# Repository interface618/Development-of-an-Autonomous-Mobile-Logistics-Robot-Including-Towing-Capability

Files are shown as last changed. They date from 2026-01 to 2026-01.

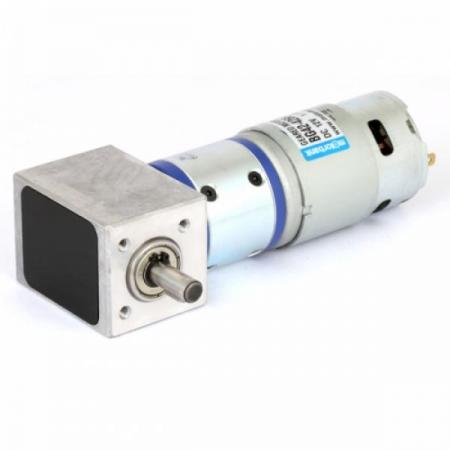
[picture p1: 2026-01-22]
HowToMake/BG42-4266.jpg

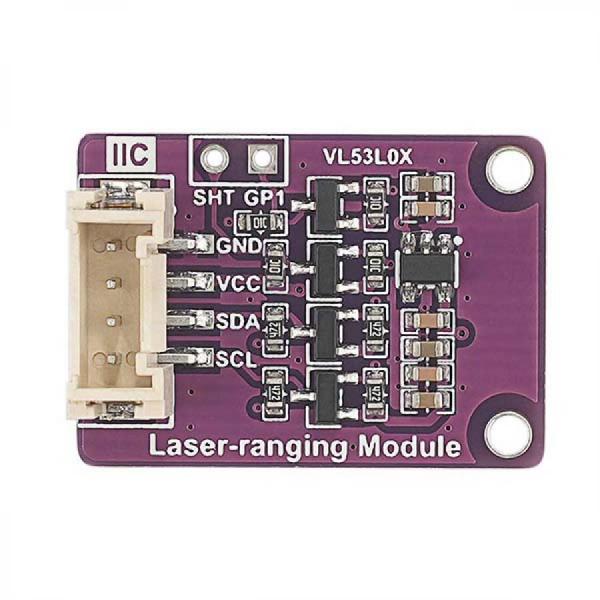
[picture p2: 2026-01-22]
HowToMake/VL53L0X.jpg

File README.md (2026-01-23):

<p align='center'>


<div align="center">
<h2>[2025] 견인기능을 포함한 물류로봇 </h2>
본 시스템은 고장 로봇 발생 시 별도의 인력 개입 없이 작업 흐름을 유지할 수 있도록 하여 다운타임을 감소시키고, 운영 비용 절감과 처리 효율 향상을 가능하게 한다. 더 나아가 로봇 간 협업 기반 자동 복구 체계를 구축함으로써 물류 시스템의 복원 탄력성과 고가용성 확보에 기여하며, 스마트 물류센터 및 무인 물류 환경으로의 확장 가능성을 제공한다.
</div>

## 목차
  - [개요](#개요) 
  - [작품 설명](#작품-설명)
  - [작품 작동 방식](#작품-작동-방식)
  - [역할 및 내용](#역할-및-내용)
  - [트러블 슈팅](#트러블-슈팅)
  - [코멘트](#코멘트)

## 개요
- 프로젝트 이름: 견인기능을 포함한 물류로봇
- 프로젝트 기간: 2025.01-2025.12
- 개발 엔진 및 언어: C & C++ & Python 
- 멤버: Interface (이윤승 ,박승규 ,최성원 ,김혁진)

## 작품 설명
본 작품은 자율이동로봇(AMR) 환경에서 고장 로봇을 정상 로봇이 자율적으로 인식하고 도킹·견인하여 물류 작업 흐름을 유지하는 자동 복구형 협업 로봇 시스템이다. 다중 센서 융합 기반 정렬 및 결합 메커니즘과 견인 모드 전환에 따른 제어 파라미터 자동 조정을 통해 하중 변화에 안정적으로 대응할 수 있도록 설계되었다. 이를 통해 물류센터 내 작업 중단을 최소화하고 운영 안정성과 고가용성을 확보한다.

## 작품 작동 방식


https://youtu.be/UkVe2rLXZ-U<br>

또는 demonstration video참조<br>

## 역할 및 내용

<table align="center">
  <thead>
    <tr>
      <th align="center">이름</th>
      <th align="center">역할</th>
      <th align="center">내용</th>
    </tr>
  </thead>
  <tbody>
    <tr>
      <td nowrap align="center">이윤승</td>
      <td align="center">프로젝트 총괄<br>견인 시 주행 안정화 알고리즘 개발<br>멀티로봇 시스템 개발<br>관제 시스템 개발</td>
      <td align="center">견인 시 주행 불안정성 완화를 위한 알고리즘 개발<br>멀티 로봇 제어를 위한 환경 구축<br>멀티로봇의 작업 스케쥴러 생성<br>관제시스템 UI 제작</td>
    </tr>
    <tr>
      <td nowrap align="center">박승규</td>
      <td align="center">모터 제어<br>센서 데이터 수집</td>
      <td align="center">STM32 기반 엔코더 속도 측정 및 모터 PWM 제어 루프 구현<br>목표 선속도/각속도 추종을 위한 증분형 PID 제어기 적용<br>견인/비견인 모드 전환 시 PID 게인 자동 스위칭 구조 설계<br>엔코더 값을 이용해 Dead-reckoning 오도메트리로 (x, y, yaw) 위치를 추정<br>IMU + 2D LiDAR EKF 융합으로 장기 드리프트 보정</td>
    </tr>
    <tr>
      <td nowrap align="center">최성원</td>
      <td align="center">영상인식 장치 제작<br>자율주행 알고리즘 개발<br>로봇정렬</td>
      <td align="center">카메라 기반 영상 인식 장치 설계 및 ROS2 연동, 로봇 전방 환경 및<br> 도킹 대상 인식을 위한 영상 처리 파이프라인 구성<br>
영상 인식 결과를 이용한 로봇 정렬 알고리즘 설계<br>
목표 위치·각도 오차에 따른 단계적 접근 로직 구성</td>
    </tr>
    <tr>
      <td nowrap align="center">김혁진</td>
      <td align="center">외관 제작<br>내부 설계 제작<br>회로도 제작<br>센서 데이터 수집</td>
      <td align="center">3D프린터를 이용한 외관제작<br>소자간의 밀집도가 높은 회로도 제작<br>회로도, 베터리, 젯슨오린나노 등 모듈간의 밀집도높은 내부 설계</td>
    </tr>
  </tbody>
</table>

## 트러블 슈팅
- **견인 모드에서 주행 불안정(피시테일) 발생**
  - 문제: 고장 로봇을 견인해 안전/정비 구역으로 이동 중, 피시테일이 발생하여 경로를 이탈함.
  - 원인: 견인 하중이 후방에 집중되면서 yaw 관성 및 응답 지연이 증가해, 기존 경로추종 제어에서 회전 오버슈트가 반복적으로 증폭됨.
  - 해결: 경로 상 2개 예측점으로 목표 방향각(heading angle)을 atan2 기반으로 계산하고, 목표 방향각(heading angle)이 임계각과 비교하여 초과하면 선속도를 제한한 뒤 각속도 우선으로 heading을
          먼저 정렬하고, 정렬 완료 후 경로 추종을 재개하도록 제어 로직을 분기함.
  - 결과: 동일 조건 반복 시험에서 경로 평균 오차가 0.4 m → 0.1 m로 감소함.
 
- **로봇의 크기와 무게 문제**
  - 문제: 로봇의 크기와 무게가 예상보다 커 줄일 필요가 생겼습니다.
  - 원인: 필요이상의 많은 소자를 사용하고 소자간의 밀집도가 떨어져 로봇 모델의 크기가 커졌습니다.
  - 해결: 중요도가 떨어지는 소자를 줄이고 소자간의 밀집도를 중심으로 재설계를 했습니다.
  - 결과: 로봇 모델의 무게를 10 ~ 11kg에서 7kg로 줄이고 크기도 줄였습니다.
 
- **후크모양에서 생기는 전류문제**
  - 문제: 견인이 성공하는 구역을 넓게하고 피견인 로봇을 높게 들게 설계를 할시 엑추에이터가 너무 많은 전류를 필요로하는 문제가 생겼습니다.
  - 원인: 2개의 엑추에이터에서 견인을 하는것을 1개의 지지대와 1개의 엑추에이터로 견인을 하게 재설계를 하여 문제가 발생하였습니다.
  - 해결: 후크구조에 임의로 3가지의 변수를 만들어 변수의 길이와 각도를 조절하며 최적의 후크구조를 찾아 해결하였습니다.
  - 결과: 최대 전류 0.1A로 견인을 할수있게 되었습니다.

- **견인 모드 하중 변화로 인한 주행 오차 증가**
  - **문제:** 견인 상태에서 속도·자세(heading) 오차가 커지며 경로 추종 안정성이 저하됨
  - **원인:** 견인 하중 증가로 시스템 동특성(관성/저항)이 변해 기존 PID 이득으로는 추종 성능이 부족함
  - **해결:** **견인 모드 전용 PID 제어 이득을 재조정(튜닝)**하고, 견인/비견인 모드에 따라 이득을 분리 적용
  - **결과:** 견인 주행 시 속도·자세 오차가 감소하고 경로 추종이 안정화됨

- **Dead-reckoning 기반 오도메트리 누적 드리프트**
  - **문제:** 장시간 주행 시 (x, y, yaw) 추정값이 누적 오차로 인해 실제 위치와 점점 벌어짐
  - **원인:** 엔코더 기반 Dead-reckoning은 슬립, 노면 변화, 엔코더/시간 동기 오차가 누적되어 장기 드리프트가 발생함
  - **해결:** IMU + 2D LiDAR를 EKF로 융합하여 오도메트리 예측값을 센서 측정으로 주기적으로 보정
  - **결과:** 장기 드리프트가 억제되어 위치추정 신뢰도가 향상되고 도킹/견인 시 정렬 안정성이 개선됨

  **영상 인식 기반 로봇 정렬 오차 및 인식 불안정성**
  - 문제: 조명·각도·가림(occlusion) 영향으로 영상 인식 기반 상대 위치/각도 추정이 흔들려 도킹 정렬이 불안정해짐

  - 원인: 단일 카메라 인식은 환경 변화에 민감하고 프레임 간 추정값이 튀어 제어 입력이 급격히 변할 수 있음

  - 해결: 영상 인식 결과를 정렬 목표값으로 사용하되 레이저 센서 등 보조 정보로 제어를 안정화하고 인식 노이즈를 완화

  - 결과: 인식 불안정이 줄어 정렬 성공률이 향상되고 도킹/견인 단계 결합 신뢰도가 개선됨
  
## 코멘트

- PID 게인을 실험적으로 조정해 성능을 맞췄지만, 시간·환경 제약으로 충분한 반복 실험 데이터를 쌓지 못한 점이 아쉬웠습니다. 다음에는 더 다양한 조건에서 데이터를 축적해 근거 기반으로 최적 게인을 도출하고 싶습니다.
- 너무 회로도와 내부 설계 밀집도만 집중해서 내부온도와 같이 중요한 부분을 놓친게 많아 아쉽다.
- 게인과 임계값을 경험적으로 맞춰 동작은 확보했지만, 하중/바닥 마찰/배터리 전압 변화까지 포함한 체계적인 튜닝 실험과 데이터 기반 최적화가 부족했다. 동일 조건 반복 실험을 통해 최적의 게인 값을 구하여 로봇이 안정적이게 움직일 수 있도록 시도 해 볼 가치가 있다.
- ArUco 마커 기반 인식은 정렬 정확도가 높고 구현이 간단하다는 장점이 있으나, 마커 훼손·가림·부착 관리가 필요한 구조적 한계가 있다. 본 연구에서는 해당 방식에 의존하였다는 점에서 실제 현장 적용성을 충분히 고려하지 못한 아쉬움이 있다. 향후에는 로봇의 형상과 외관 특징을 학습한 객체 인식 모델을 활용하여 마커 없는 정렬 방식을 적용함으로써 시스템의 실용성과 확장성을 높이고자 한다.
- 실물 로봇을 만들기전에 Gazebo 시뮬레이션을 사용해보고 했으면 시행착오가 덜 했을것 같다는 생각이 들었다 다음에는 시뮬레이션을 돌려보고 실물 로봇 제작을 해야할것 같다.
- 생각보다 C/C++/Python을 사용을 잘 못하는 것 같다 코딩 테스트나 공부를 더해야겠다는 생각이 들었다.
- 내가 만든 알고리즘을 논문이나 발표자료에 수식으로 표현해야하는데 수학적인 지식이 부족해서 표현하는데 힘들었던 것 같다 선형대수학과 미적분학, 확률과 통계에 대한 공부를 더 해야겠다는 생각이 들었다

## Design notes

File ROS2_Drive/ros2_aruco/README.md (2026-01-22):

# ros2_aruco

ROS2 Wrapper for OpenCV Aruco Marker Tracking

This package depends on a recent version of OpenCV python bindings and transforms3d library:

```
pip3 install opencv-contrib-python transforms3d
```

## ROS2 API for the ros2_aruco Node

This node locates Aruco AR markers in images and publishes their ids and poses.

Subscriptions:
* `/camera/image_raw` (`sensor_msgs.msg.Image`)
* `/camera/camera_info` (`sensor_msgs.msg.CameraInfo`)

Published Topics:
* `/aruco_poses` (`geometry_msgs.msg.PoseArray`) - Poses of all detected markers (suitable for rviz visualization)
* `/aruco_markers` (`ros2_aruco_interfaces.msg.ArucoMarkers`) - Provides an array of all poses along with the corresponding marker ids

Parameters:
* `marker_size` - size of the markers in meters (default .0625)
* `aruco_dictionary_id` - dictionary that was used to generate markers (default `DICT_5X5_250`)
* `image_topic` - image topic to subscribe to (default `/camera/image_raw`)
* `camera_info_topic` - Camera info topic to subscribe to (default `/camera/camera_info`)
* `camera_frame` - Camera optical frame to use (default to the frame id provided by the camera info message.)

## Running Marker Detection

1. Using the launch file - parameters will be loaded from _aruco\_parameters.yaml_.
```
ros2 launch ros2_aruco aruco_recognition.launch.py
```
2. As a single ROS 2 node - you can specify parameter values at startup by adding `--ros-args -p marker_size:=.05`, for example.
```
ros2 run ros2_aruco aruco_node
```

## Generating Marker Images

```
ros2 run ros2_aruco aruco_generate_marker
```

Pass the `-h` flag for usage information: 

```
usage: aruco_generate_marker [-h] [--id ID] [--size SIZE] [--dictionary]

Generate a .png image of a specified maker.

optional arguments:
  -h, --help     show this help message and exit
  --id ID        Marker id to generate (default: 1)
  --size SIZE    Side length in pixels (default: 200)
  --dictionary   Dictionary to use. Valid options include: DICT_4X4_100,
                 DICT_4X4_1000, DICT_4X4_250, DICT_4X4_50, DICT_5X5_100,
                 DICT_5X5_1000, DICT_5X5_250, DICT_5X5_50, DICT_6X6_100,
                 DICT_6X6_1000, DICT_6X6_250, DICT_6X6_50, DICT_7X7_100,
                 DICT_7X7_1000, DICT_7X7_250, DICT_7X7_50, DICT_ARUCO_ORIGINAL
                 (default: DICT_5X5_250)
```

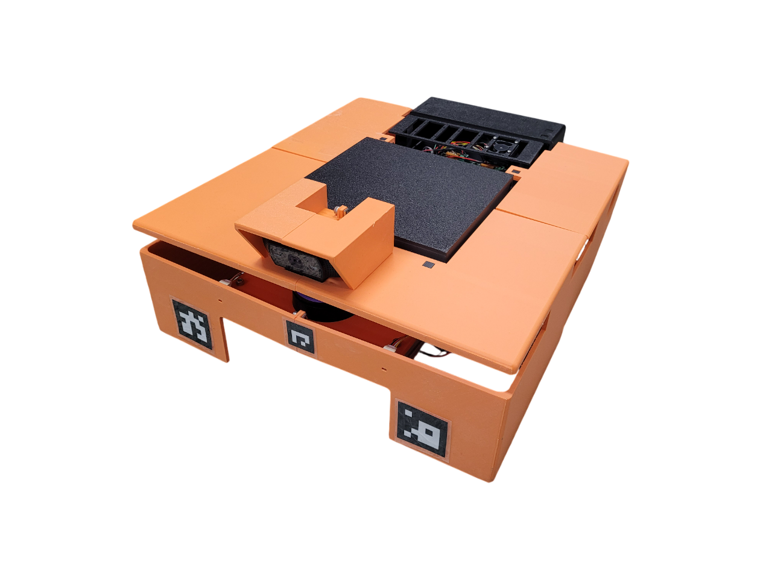
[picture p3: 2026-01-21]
3D/full1.png

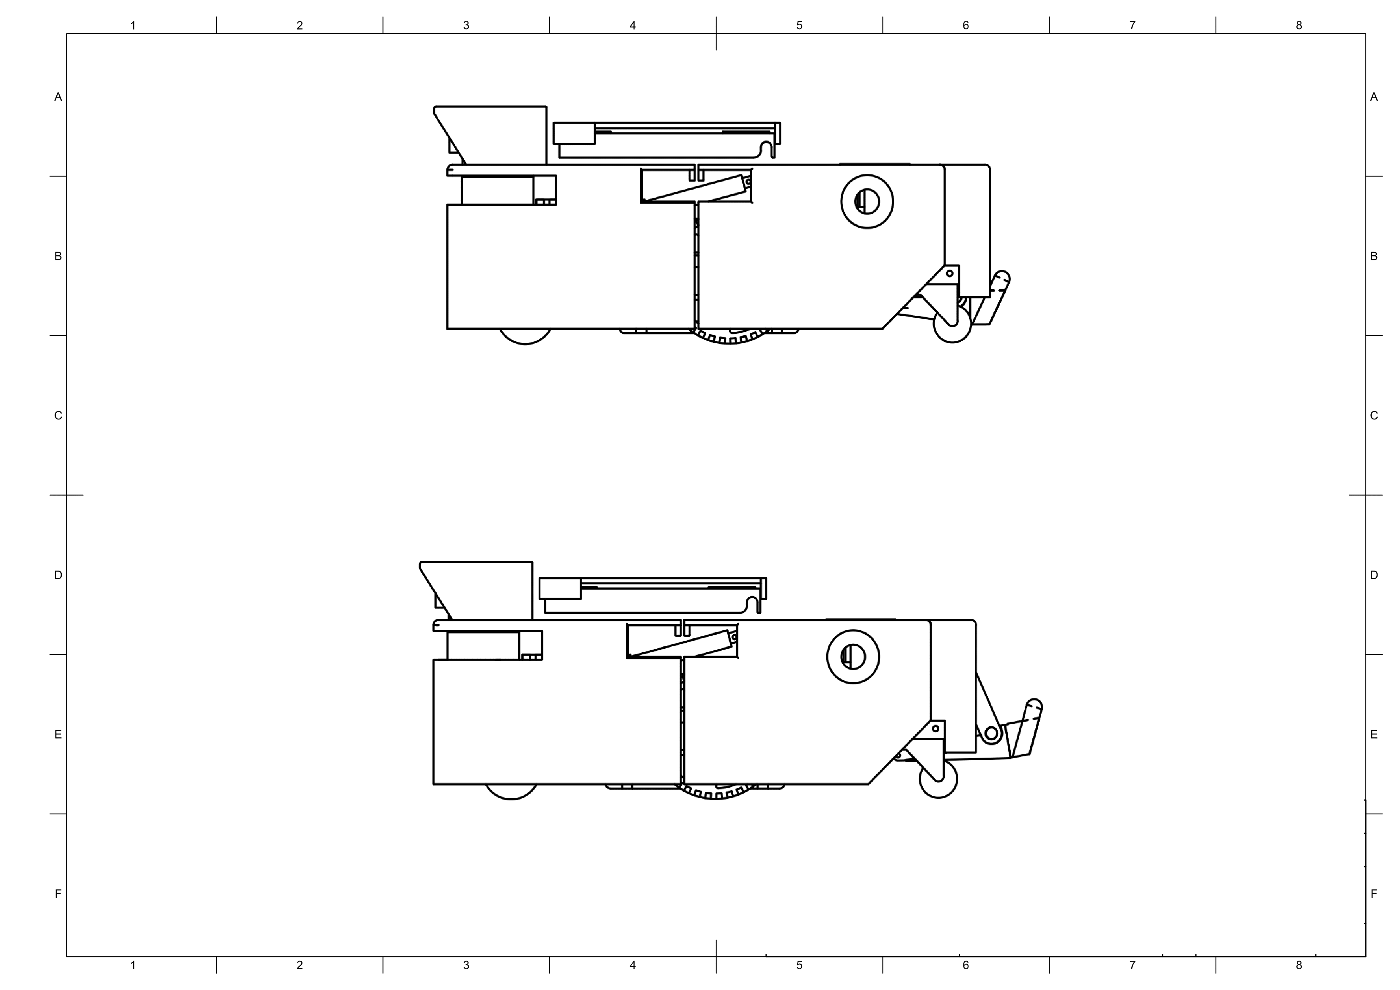
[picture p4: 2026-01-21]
3D/hook_updown.png

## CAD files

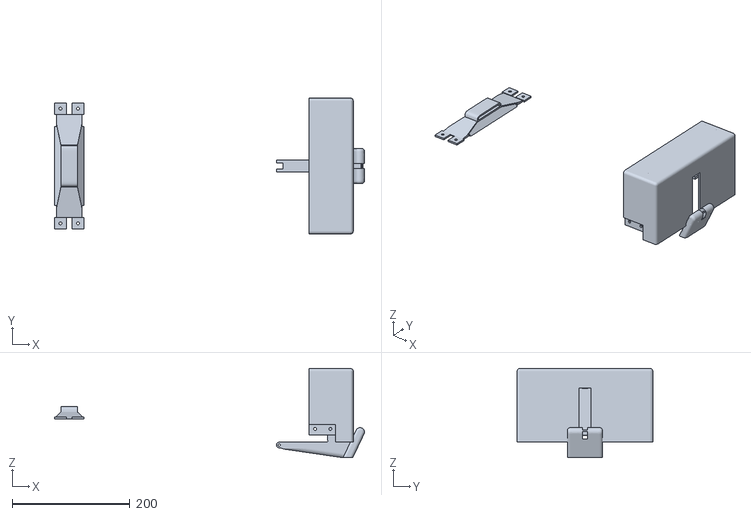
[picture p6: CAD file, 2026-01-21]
3D/hook.stl
527.3 x 231.2 x 151.6

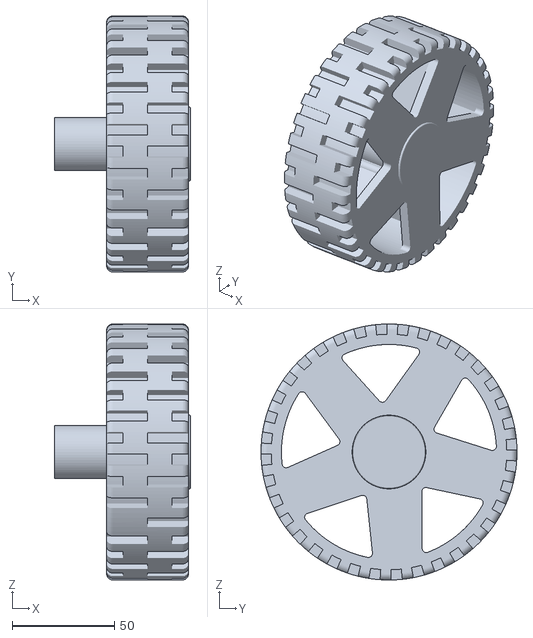
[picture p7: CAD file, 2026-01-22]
ROS2_Drive/shark_urdf/meshes/wheel.stl
66.5 x 125.0 x 125.0

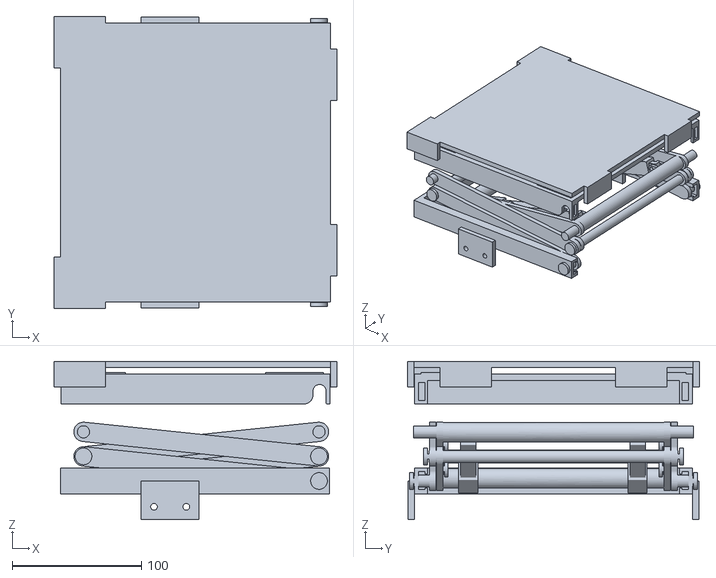
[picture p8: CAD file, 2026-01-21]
3D/lift.stl
219.0 x 226.0 x 122.6

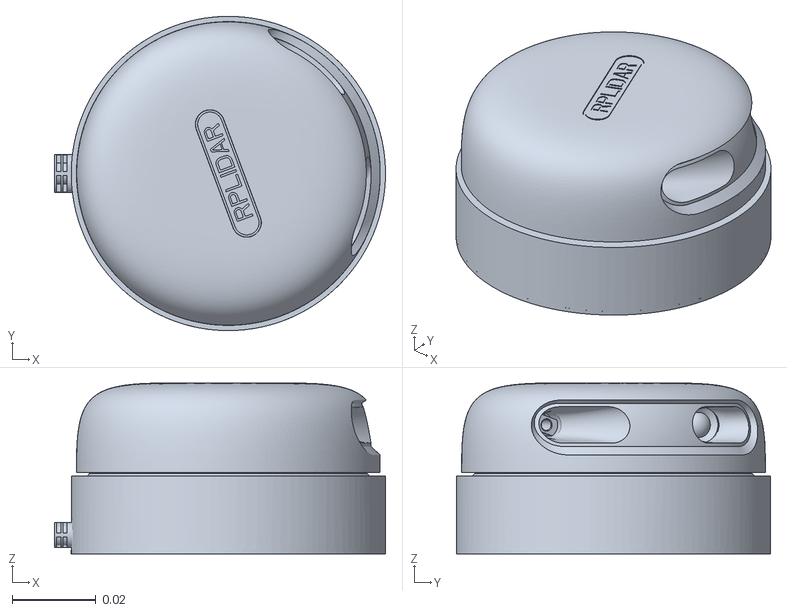
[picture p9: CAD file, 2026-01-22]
ROS2_Drive/shark_urdf/meshes/rplidar-a2.stl
0.079 x 0.075 x 0.0408

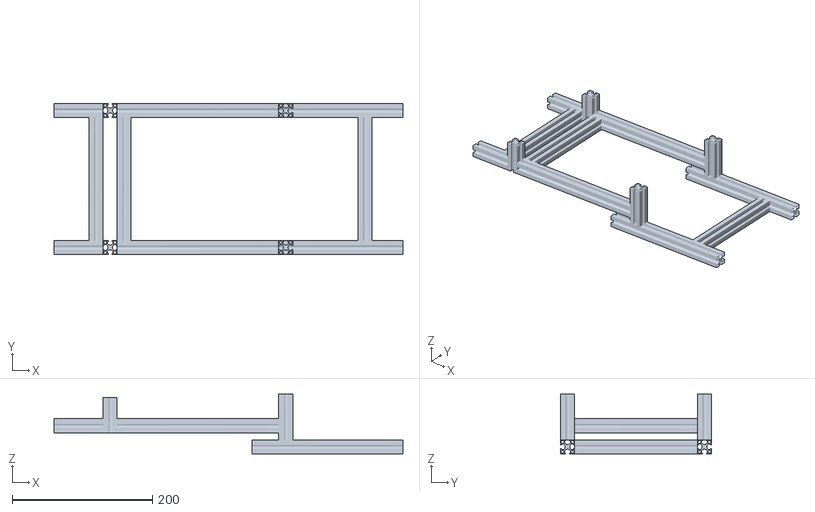
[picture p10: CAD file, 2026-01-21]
3D/frame.stl
497.0 x 215.0 x 85.0

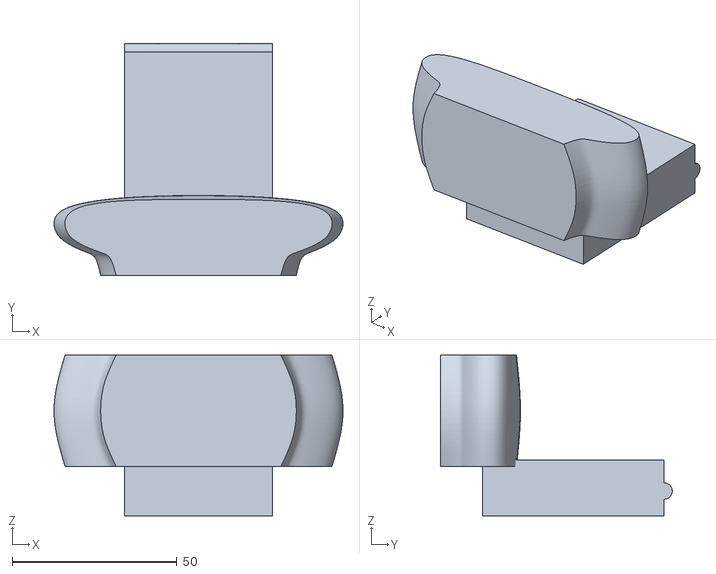
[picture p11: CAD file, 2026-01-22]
ROS2_Drive/shark_urdf/meshes/webcam.stl
87.6 x 70.2 x 48.7

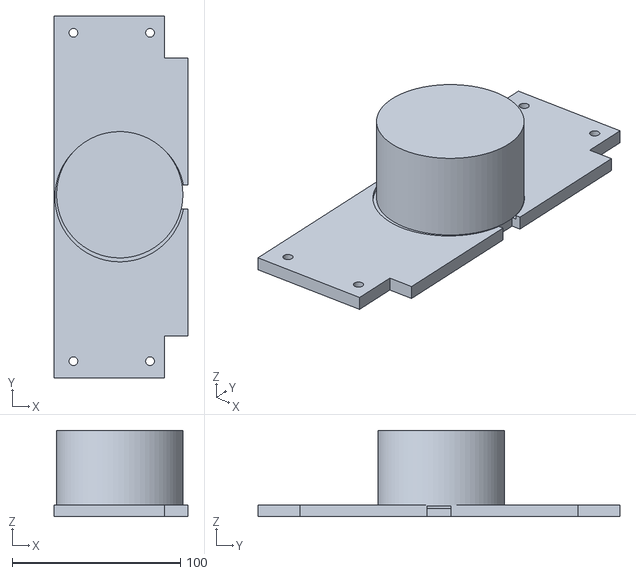
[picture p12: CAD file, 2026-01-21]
3D/lidar.stl
79.5 x 215.0 x 51.4

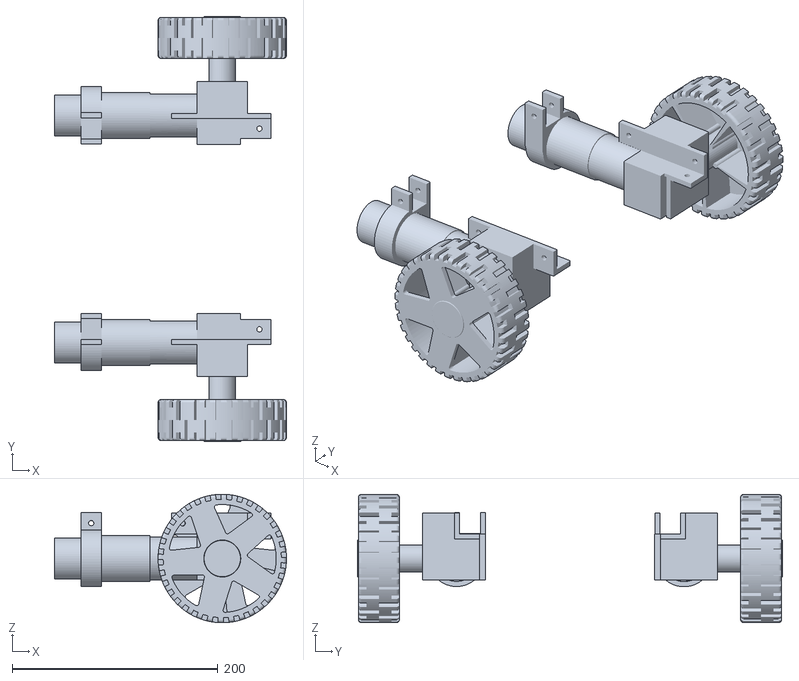
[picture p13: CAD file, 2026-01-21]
3D/motor.stl
225.8 x 413.9 x 125.0

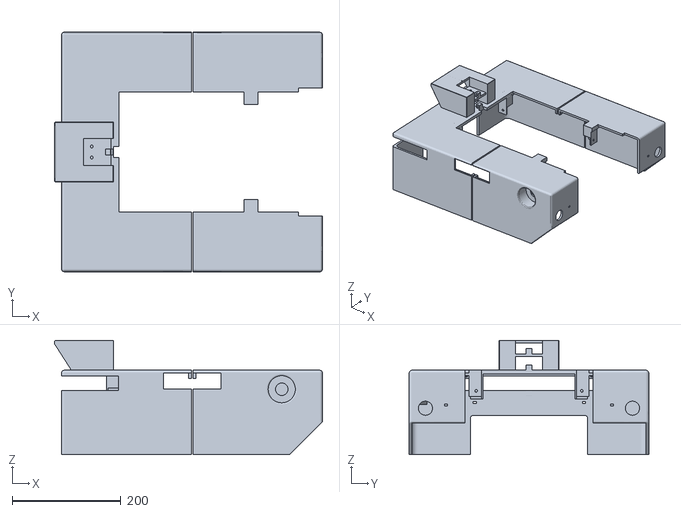
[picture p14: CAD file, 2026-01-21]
3D/bumper.stl
493.6 x 441.3 x 210.5

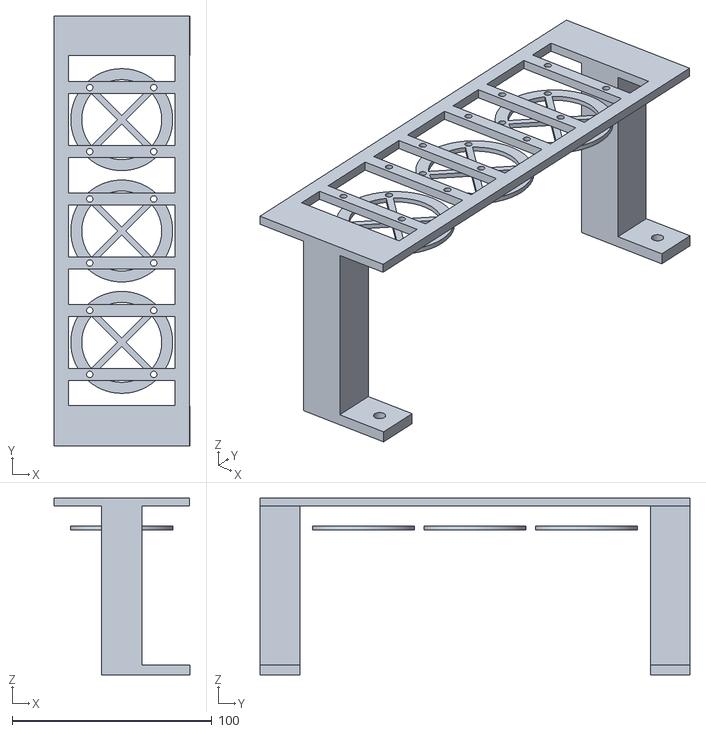
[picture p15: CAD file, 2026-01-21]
3D/cooler.stl
67.8 x 215.0 x 88.5

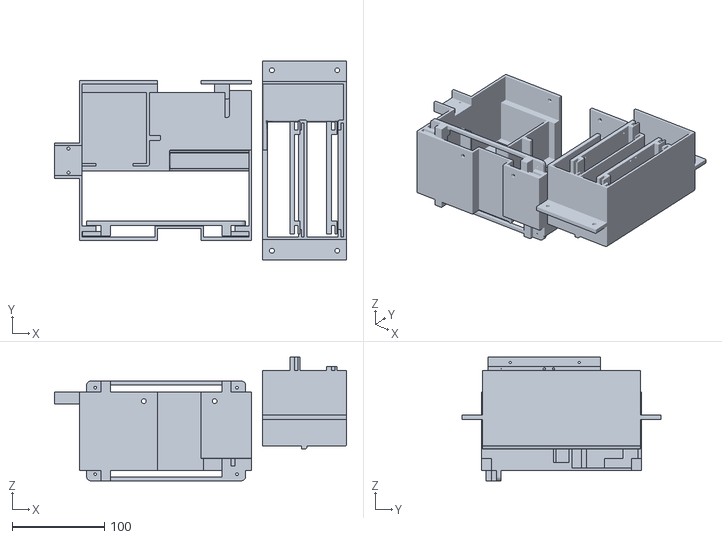
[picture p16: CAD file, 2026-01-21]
3D/box.stl
317.2 x 216.0 x 134.4

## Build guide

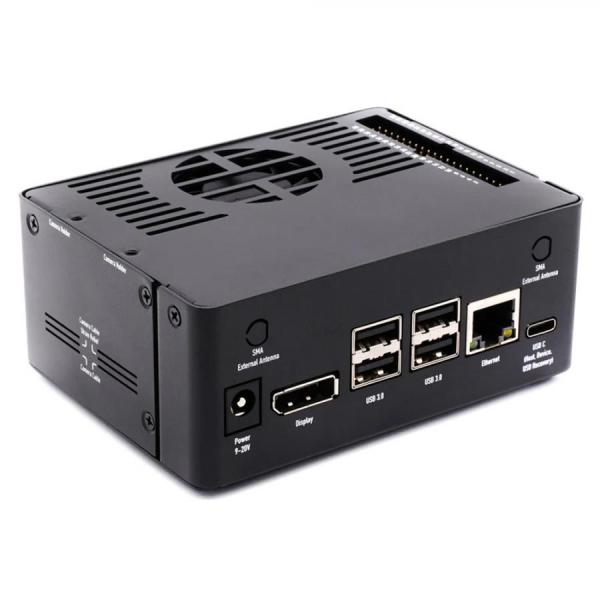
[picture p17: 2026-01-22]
HowToMake/NVIDIA Jetson Orin Nano.jpg

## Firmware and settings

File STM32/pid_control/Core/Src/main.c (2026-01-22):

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
/* Includes ------------------------------------------------------------------*/
#include "main.h"

/* USER CODE BEGIN Includes */
#include <stdio.h>
#include <math.h>
#include <stdlib.h>
#include <string.h>
#include "stm32f4xx.h"
#include "VL53L0X.h"

/* USER CODE END Includes */

/* USER CODE BEGIN PTD */
extern I2C_HandleTypeDef VL53L0X_I2C_Handler;

/* USER CODE END PTD */

I2C_HandleTypeDef hi2c1;
I2C_HandleTypeDef hi2c2;

TIM_HandleTypeDef htim2;
TIM_HandleTypeDef htim3;
TIM_HandleTypeDef htim5;

UART_HandleTypeDef huart2;

/* USER CODE BEGIN PV */
/*=======================================RAZER=======================================*/
statInfo_t_VL53L0X distanceL_stats;
statInfo_t_VL53L0X distanceR_stats;
uint16_t distanceL = 0; // volatile 추가
uint16_t distanceR = 0; // volatile 추가


#define FILTER_BUFFER_SIZE 10
volatile uint16_t distanceL_buffer[FILTER_BUFFER_SIZE] = {0};
volatile uint16_t distanceR_buffer[FILTER_BUFFER_SIZE] = {0};
int buffer_index_L = 0;
int buffer_index_R = 0;
/*=======================================RAZER=======================================*/
/* USER CODE END PV */

void SystemClock_Config(void);
static void MX_GPIO_Init(void);
static void MX_USART2_UART_Init(void);
static void MX_TIM5_Init(void);
static void MX_TIM2_Init(void);
static void MX_I2C1_Init(void);
static void MX_I2C2_Init(void);
static void MX_TIM3_Init(void);
/* USER CODE BEGIN PFP */
#ifdef __GNUC__
#define PUTCHAR_PROTOTYPE int __io_putchar(int ch)
#else
#define PUTCHAR_PROTOTYPE int fputc(int ch, FILE *f)
#endif

PUTCHAR_PROTOTYPE {
	if (ch == '\n')
		HAL_UART_Transmit(&huart2, (uint8_t*) "\r", 1, 0xFFFF);
	HAL_UART_Transmit(&huart2, (uint8_t*) &ch, 1, 0xFFFF);
	return ch;
}


/*=============================DT=============================*/
extern volatile uint32_t msTicks;   // SysTick 1ms 카운터
#define DT_S          0.039f      // 39 ms 고정 주기
/*=============================DT=============================*/

/*=========================Encoder value=========================*/
volatile int32_t left_encoder_value = 0;    //left
volatile int32_t right_encoder_value  = 0;  //right

volatile int32_t prev_count_L = 0;
volatile int32_t prev_count_R = 0;
/*=========================Encoder value=========================*/

/*============================motor============================*/
#define WHEEL_RADIUS    0.0625f    // 바퀴 반지름 (단위: m)
#define WHEEL_BASE      0.33f    // 바퀴 간 거리 (단위: m)
#define ENCODER_RES     3172       // 엔코더 분해능 (4체배 적용된 값)
volatile int32_t tow = 0;
volatile int32_t tow_applied = 0;
/*============================motor============================*/

/*=============================PID=============================*/
float Kp = 4, Kd = 1.6, Ki = 8;
float P_term = 0, D_term = 0, I_term = 0;
float pid = 0;

float Kp_a = 5, Kd_a = 1.3, Ki_a = 6.25;
float P_term_a = 0, D_term_a = 0, I_term_a = 0;
float pid_a = 0;

float error = 0;
float previous_error = 0;
float old_error = 0;

float error_a = 0;
float previous_error_a = 0;
float old_error_a = 0;

float speed = 0;
float speed_r = 0;

double angle = 0.0019808276504349264;   // will fix (rad/count)

/*=============================MID=============================*/
volatile int32_t delta_cnt_L = 0;
volatile int32_t delta_cnt_R = 0;
float   dtheta_L    = 0.0f;    // [rad]
float   dtheta_R    = 0.0f;    // [rad]
float   dist_L      = 0.0f;    // [m]
float   dist_R      = 0.0f;    // [m]
float   s_step      = 0.0f;    // [m/period]
float   theta_step  = 0.0f;    // [rad/period]
float   v_meas      = 0.0f;    // [m/s]
float   w_meas      = 0.0f;    // [rad/s]
/*=============================MID=============================*/

/*=============================PID=============================*/


/*=============================USART=============================*/
char rx_buffer[256];
char rx_data;
int rx_index = 0;

int stop_flag = 0;
int sent_flag = 0;  // 전송 여부 상태 저장

// 1. ROS에서 받은 선속도/각속도 값 (단위: m/s, rad/s)
float cmd_vel_x = 0.0;  // v
float cmd_vel_z = 0.0;  // w

/*=============================USART=============================*/

/*=============================DIR=============================*/
void check_move_state();
void check_move_state_r();
void motorControl(int in1, int in2);
void motorControl_r(int in1, int in2);

int control_1 = 0, control_2 = 1;
int control_1_r = 1, control_2_r = 0;

int move_state = 0;  // front:0 back:1
int move_state_r = 0;
/*=============================DIR=============================*/

/*=============================PWM=============================*/
void Pwm_Left(int pwm_input);
void Pwm_Right(int pwm_input);
void check_pwm();
void check_pwm_r();
/*=============================PWM=============================*/


/*=============================RK2=============================*/
double odom_x = 0.0;     // [m]
double odom_y = 0.0;     // [m]
double odom_th = 0.0;    // [rad]

double previous_odom_x = 0.0;
double previous_odom_y = 0.0;
double previous_odom_th = 0.0;

double value = 0.0;
double dtt = 0.0;

/*=============================RK2=============================*/

/*=============================RAZER=============================*/
void apply_sensor_config(void);
uint16_t get_filtered_distance(volatile uint16_t* buffer, int* index, uint16_t new_distance);
/*=============================RAZER=============================*/
/*=============================SWITCH=============================*/
void limited_switch();
int switch_flag = 0;
int switch_count = 0;
/*=============================SWITCH=============================*/

/* USER CODE END PFP */

/**
  * @brief  The application entry point.
  * @retval int
  */
int main(void)
{

  /* MCU Configuration--------------------------------------------------------*/

  /* Reset of all peripherals, Initializes the Flash interface and the Systick. */
  HAL_Init();

  /* Configure the system clock */
  SystemClock_Config();

  /* Initialize all configured peripherals */
  MX_GPIO_Init();
  MX_USART2_UART_Init();
  MX_TIM5_Init();
  MX_TIM2_Init();
  MX_I2C1_Init();
  MX_I2C2_Init();
  MX_TIM3_Init();
  /* USER CODE BEGIN 2 */

  /*----------------------------------------------------*/
  HAL_TIM_PWM_Start(&htim5, TIM_CHANNEL_1);
  HAL_TIM_PWM_Start(&htim5, TIM_CHANNEL_2);


  /*----------------------------------------------------*/

  /*----------------------------------------------------*/
  motorControl(control_1,  control_2);
  motorControl_r(control_1_r, control_2_r);

  /*----------------------------------------------------*/
  HAL_UART_Receive_IT(&huart2, (uint8_t*)&rx_data, 1);
  HAL_TIM_Base_Start_IT(&htim2);
  /*----------------------------------------------------*/
  SystemCoreClockUpdate();
  SysTick_Config(SystemCoreClock / 1000);
  /*----------------------------------------------------*/

	//  // --- 센서 초기화 ---
	HAL_GPIO_WritePin(RAZER_POWER1_GPIO_Port, RAZER_POWER1_Pin, GPIO_PIN_SET);
	HAL_GPIO_WritePin(RAZER_POWER2_GPIO_Port, RAZER_POWER2_Pin, GPIO_PIN_SET);

	VL53L0X_I2C_Handler = hi2c1;
	if (initVL53L0X(1, &hi2c1)) {
		apply_sensor_config(); // 안정적인 330ms 설정 적용
	}

	VL53L0X_I2C_Handler = hi2c2;
	if (initVL53L0X(1, &hi2c2)) {
		apply_sensor_config();
	}

	// --- 첫 측정 시작 ---
	VL53L0X_I2C_Handler = hi2c1;
	startSingleMeasurement_nonBlocking();
	VL53L0X_I2C_Handler = hi2c2;
	startSingleMeasurement_nonBlocking();
  /*----------------------------------------------------*/
  /* USER CODE END 2 */

  /* Infinite loop */
  /* USER CODE BEGIN WHILE */
	while (1) {



		limited_switch();

		//방향 제어
		motorControl(control_1, control_2);
		motorControl_r(control_1_r, control_2_r);
		//PWM 제어
		Pwm_Left(fabsf(speed));
		Pwm_Right(fabsf(speed_r));

		/******** PID only + v,w print (전역 변수만 사용) ********/
		if (msTicks >= 39) {
			dtt = msTicks;

			/*************************** TOW ******************************/
			if (tow == 1 && tow_applied == 0)
			{
				//KP,KI,KD 값 변경
			    Kp   = Kp   * 1.25f;   Ki   = Ki   * 1.20f;   Kd   = Kd   * 0.90f;
			    Kp_a = Kp_a * 1.30f;   Ki_a = Ki_a * 1.20f;   Kd_a = Kd_a * 0.90f;

			    previous_error = old_error = 0.0f;
			    previous_error_a = old_error_a = 0.0f;

			    tow_applied = 1;
			}
			/*************************** TOW ******************************/

			/*************************** RAZER ******************************/
			// --- 센서 상태 확인 및 데이터 수신 (논블로킹) ---
			VL53L0X_I2C_Handler = hi2c1;
			if (isMeasurementReady()) {
				uint16_t raw_distanceL = readMeasurementResult(
						&distanceL_stats);
				// 필터링 및 범위 제한 적용
				if (distanceL_stats.rangeStatus == 0
						|| distanceL_stats.rangeStatus == 11) {
					distanceL = get_filtered_distance(distanceL_buffer,
							&buffer_index_L, raw_distanceL);
				}
				startSingleMeasurement_nonBlocking(); // 다음 측정 시작
			}

			VL53L0X_I2C_Handler = hi2c2;
			if (isMeasurementReady()) {
				uint16_t raw_distanceR = readMeasurementResult(
						&distanceR_stats);
				if (distanceR_stats.rangeStatus == 0
						|| distanceR_stats.rangeStatus == 11) {
					distanceR = get_filtered_distance(distanceR_buffer,
							&buffer_index_R, raw_distanceR);
				}
				startSingleMeasurement_nonBlocking(); // 다음 측정 시작
			}
			/*************************** RAZER ******************************/
			// 1) 이번 주기 엔코더 증가량
			delta_cnt_L = left_encoder_value - prev_count_L;
			delta_cnt_R = right_encoder_value - prev_count_R;
			prev_count_L = left_encoder_value;
			prev_count_R = right_encoder_value;

			// 2) 바퀴 각도[rad] → 선형 이동[m]
			dtheta_L = (float) delta_cnt_L * (float) angle;  // angle: rad/count
			dtheta_R = (float) delta_cnt_R * (float) angle;
			dist_L = dtheta_L * WHEEL_RADIUS;
			dist_R = dtheta_R * WHEEL_RADIUS;

			// 3) 이번 주기 전진/회전 변위
			s_step = 0.5f * (dist_R + dist_L);            // [m/period]
			theta_step = (dist_R - dist_L) / WHEEL_BASE;      // [rad/period]

			/******************** RK2 ***********************/
			value = previous_odom_th + (theta_step * 0.5f);
			odom_x = previous_odom_x + (s_step * cosf(value));
			odom_y = previous_odom_y + (s_step * sinf(value));
			odom_th = previous_odom_th + theta_step;

			previous_odom_x = odom_x;
			previous_odom_y = odom_y;
			previous_odom_th = odom_th;

			// 4) 측정 속도 환산
			v_meas = s_step / (dtt * 0.001f);                       // [m/s]
			w_meas = theta_step / (dtt * 0.001f);                     // [rad/s]

			/******************** PID ***********************/
			// 목표속도 - 측정속도
			error = (cmd_vel_x - v_meas);
			error_a = (cmd_vel_z - w_meas);

			// 증분형(Delta) 형태
			P_term = (error - previous_error) * Kp;
			D_term = (error - 2.0f * previous_error + old_error) * Kd;
			I_term = error * Ki;
			pid = P_term + D_term + I_term;

			P_term_a = (error_a - previous_error_a) * Kp_a;
			D_term_a = (error_a - 2.0f * previous_error_a + old_error_a) * Kd_a;
			I_term_a = error_a * Ki_a;
			pid_a = P_term_a + D_term_a + I_term_a;

			if (stop_flag == 0) {
				// 차동 결합: 선형(pid) ± 회전(pid_a)
				speed = speed + pid - pid_a;
				speed_r = speed_r + pid + pid_a;
			} else {
				speed = speed - (speed) / 5.0f;
				speed_r = speed_r - (speed_r) / 5.0f;
			}

			// 상태 갱신
			old_error = previous_error;
			old_error_a = previous_error_a;
			previous_error = error;
			previous_error_a = error_a;

			// PWM/상태 체크
			check_pwm();
			check_pwm_r();
			check_move_state();
			check_move_state_r();

			if (cmd_vel_x == 0 && cmd_vel_z == 0) {
				stop_flag = 1;
			} else {
				stop_flag = 0;
			}

			printf("# %f %f %f %f %f %f | %f %f %d\n", odom_x, odom_y, odom_th,
					dtt, v_meas, w_meas, (float)distanceL, (float)distanceR, switch_flag);


		}

    /* USER CODE END WHILE */

    /* USER CODE BEGIN 3 */
	}
  /* USER CODE END 3 */
}

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
/* USER CODE BEGIN 4 */

/*=========================Encoder value=========================*/
void HAL_GPIO_EXTI_Callback(uint16_t GPIO_Pin)
{

    if (GPIO_Pin == GPIO_PIN_15) // Left A
    {
        if (HAL_GPIO_ReadPin(GPIOB, GPIO_PIN_15) == HAL_GPIO_ReadPin(GPIOB, GPIO_PIN_14))
        {
            left_encoder_value--;
        }
        else
        {
            left_encoder_value++;
        }
    }
    else if (GPIO_Pin == GPIO_PIN_14) // Left B
    {
        if (HAL_GPIO_ReadPin(GPIOB, GPIO_PIN_15) == HAL_GPIO_ReadPin(GPIOB, GPIO_PIN_14))
        {
            left_encoder_value++;
        }
        else
        {
            left_encoder_value--;
        }
    }

    else if (GPIO_Pin == GPIO_PIN_12) // Right A
    {
        if (HAL_GPIO_ReadPin(GPIOA, GPIO_PIN_12) == HAL_GPIO_ReadPin(GPIOA, GPIO_PIN_11))
        {
            right_encoder_value++;
        }
        else
        {
            right_encoder_value--;
        }
    }
    else if (GPIO_Pin == GPIO_PIN_11) // Right B
    {
        if (HAL_GPIO_ReadPin(GPIOA, GPIO_PIN_12) == HAL_GPIO_ReadPin(GPIOA, GPIO_PIN_11))
        {
            right_encoder_value--;
        }
        else
        {
            right_encoder_value++;
        }
    }


    UNUSED(GPIO_Pin); // Prevent unused warning
}
/*=========================Encoder value=========================*/


/*=============================USART=============================*/
void HAL_UART_RxCpltCallback(UART_HandleTypeDef *huart) {
	if (huart->Instance == USART2) {
		if (rx_data != '\n') {
			rx_buffer[rx_index++] = rx_data;
		}
		else {
			rx_buffer[rx_index] = '\0';

			if (rx_buffer[0] == '1') {
				// 선속도 (cmd_vel_x) 추출
				char first_number[10];
				strncpy(first_number, &rx_buffer[2], 9);
				first_number[9] = '\0';
				cmd_vel_x = atof(first_number);
				if (rx_buffer[1] == '0') {
					cmd_vel_x = -cmd_vel_x;
				}

				// 각속도 (cmd_vel_z) 추출
				char second_number[10];
				strncpy(second_number, &rx_buffer[12], 9);
				second_number[9] = '\0';
				cmd_vel_z = atof(second_number);
				if (rx_buffer[11] == '0') {
					cmd_vel_z = -cmd_vel_z;
				}
			}
			else if (rx_buffer[0] == '3')
			{
                // 00
				HAL_GPIO_WritePin(GPIOA, GPIO_PIN_8, GPIO_PIN_RESET);
				HAL_GPIO_WritePin(GPIOA, GPIO_PIN_9, GPIO_PIN_RESET);
				HAL_GPIO_WritePin(GPIOC, GPIO_PIN_8, GPIO_PIN_RESET);
								HAL_GPIO_WritePin(GPIOC, GPIO_PIN_9, GPIO_PIN_RESET);
			}
			else if (rx_buffer[0] == '4')
			{
				//10
				HAL_GPIO_WritePin(GPIOA, GPIO_PIN_8, GPIO_PIN_SET);
				HAL_GPIO_WritePin(GPIOA, GPIO_PIN_9, GPIO_PIN_RESET);
				HAL_GPIO_WritePin(GPIOC, GPIO_PIN_8, GPIO_PIN_SET);
								HAL_GPIO_WritePin(GPIOC, GPIO_PIN_9, GPIO_PIN_RESET);
			}
			else if (rx_buffer[0] == '5')
			{

				//01
				HAL_GPIO_WritePin(GPIOA, GPIO_PIN_8, GPIO_PIN_RESET);
				HAL_GPIO_WritePin(GPIOA, GPIO_PIN_9, GPIO_PIN_SET);

				HAL_GPIO_WritePin(GPIOC, GPIO_PIN_8, GPIO_PIN_RESET);
								HAL_GPIO_WritePin(GPIOC, GPIO_PIN_9, GPIO_PIN_SET);
			}
			else if (rx_buffer[0] == '6')
			{
				NVIC_SystemReset();
			}
			// 수신 버퍼 초기화
			rx_index = 0;
			memset(rx_buffer, 0, sizeof(rx_buffer));
		}
	}

	HAL_UART_Receive_IT(&huart2, (uint8_t*)&rx_data, 1);
}
/*=============================USART=============================*/

/*=============================TIM=============================*/
void HAL_TIM_PeriodElapsedCallback(TIM_HandleTypeDef *htim) {
	if (htim->Instance == TIM2) {
		if (msTicks > 39) {
			msTicks = 0;
		}

	}
	if (htim->Instance == TIM3) {

		if (HAL_GPIO_ReadPin(GPIOC, GPIO_PIN_7) == 0) {
			if (switch_flag == 0) {
				switch_count++;
			}

			if (switch_count >= 50000) {

			    tow = 1;
				switch_count = 0;
				switch_flag = 1;
			}

		} else {
			switch_count = 0;
			switch_flag = 0;
		}

	}
}
/*=============================TIM=============================*/

/*=============================DIR=============================*/
void check_move_state() {
  if (speed >= 0) {
    move_state = 0;
    control_1 = 0; control_2 = 1;  // Forward
  } else {
    move_state = 1;
    control_1 = 1; control_2 = 0;  // Reverse
  }
}

void check_move_state_r() {
  if (speed_r >= 0) {
    move_state_r = 0;
    control_1_r = 1; control_2_r = 0;  // Forward
  } else {
    move_state_r = 1;
    control_1_r = 0; control_2_r = 1;  // Reverse
  }
}


void motorControl(int in1, int in2) {
	GPIO_PinState state1=GPIO_PIN_RESET,state2=GPIO_PIN_RESET;
	if(in1==1){
		state1=GPIO_PIN_SET;
	}
	else{
		state1=GPIO_PIN_RESET;
	}
	if(in2==1){
		state2=GPIO_PIN_SET;
	}
	else{
		state2=GPIO_PIN_RESET;
	}
	HAL_GPIO_WritePin(GPIOB, GPIO_PIN_13, state1);
	HAL_GPIO_WritePin(GPIOC, GPIO_PIN_4, state2);

}

void motorControl_r(int in1, int in2) {
	GPIO_PinState state1=GPIO_PIN_RESET,state2=GPIO_PIN_RESET;
	if(in1==1){
		state1=GPIO_PIN_SET;
	}
	else{
		state1=GPIO_PIN_RESET;
	}
	if(in2==1){
		state2=GPIO_PIN_SET;
	}
	else{
		state2=GPIO_PIN_RESET;
	}
	HAL_GPIO_WritePin(GPIOC, GPIO_PIN_5, state1);
 	HAL_GPIO_WritePin(GPIOC, GPIO_PIN_6, state2);
}
/*=============================DIR=============================*/


/*=============================PWM=============================*/
void check_pwm() {
	if (speed >= 180) {
		speed = 180;
	} else if (speed <= -180) {
		speed = -180;
	}
}

void check_pwm_r() {
	if (speed_r >= 180) {
		speed_r = 180;
	} else if (speed_r <= -180) {
		speed_r = -180;
	}
}

// 왼쪽 모터 PWM 제어 (pwm_value: 0~PWM_MAX)
void Pwm_Left(int pwm_input)
{

    htim5.Instance->CCR1 = pwm_input;
}

// 오른쪽 모터 PWM 제어 (pwm_value: 0~PWM_MAX)
void Pwm_Right(int pwm_input)
{

    htim5.Instance->CCR2 = pwm_input;
}
/*=============================PWM=============================*/

/*=======================================RAZER=======================================*/
void apply_sensor_config(void)
{
    setSignalRateLimit(200);
    setVcselPulsePeriod(VcselPeriodPreRange, 14);
    setVcselPulsePeriod(VcselPeriodFinalRange, 10);
    setMeasurementTimingBudget(330000UL); // 330ms
}

// 이동 평균 필터 및 범위 제한을 적용하는 함수
uint16_t get_filtered_distance(volatile uint16_t* buffer, int* index, uint16_t new_distance)
{
    // 1. 새 값을 버퍼에 저장 (오래된 값 덮어쓰기)
    buffer[*index] = new_distance;
    *index = (*index + 1) % FILTER_BUFFER_SIZE;

    // 2. 버퍼의 평균 계산
    long sum = 0;
    int valid_samples = 0;
    for (int i = 0; i < FILTER_BUFFER_SIZE; i++) {
        // 유효한 초기값이 들어왔을 때만 평균에 포함
        if (buffer[i] > 0 && buffer[i] < 8000) {
            sum += buffer[i];
            valid_samples++;
        }
    }

    uint16_t averaged_distance = 0;
    if (valid_samples > 0) {
        averaged_distance = sum / valid_samples;
    } else {
        return 8191; // 버퍼에 유효한 값이 하나도 없으면 에러 값 반환
    }

    // 3. 거리 제한 (0 ~ 1000mm)
    if (averaged_distance > 1000) {
        averaged_distance = 1000;
    }

    return averaged_distance;
}
/*=======================================RAZER=======================================*/

/*=======================================SWITCH=======================================*/
void limited_switch()
{
	if(HAL_GPIO_ReadPin(GPIOC, GPIO_PIN_7) == 0)
	{
		HAL_TIM_Base_Start_IT(&htim3);
	}
}
/*=======================================SWITCH=======================================*/
/*----------------------------------------------------*/
/* USER CODE END 4 */
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


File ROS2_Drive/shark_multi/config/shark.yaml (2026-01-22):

shark1/amcl:
  ros__parameters:
    use_sim_time: False
    alpha1: 0.9 #0.9
    alpha2: 0.1 #0,1
    alpha3: 0.05 #0.05
    alpha4: 0.01 #0.01
    alpha5: 0.04 #0.04
    base_frame_id: "shark1/base_footprint"
    beam_skip_distance: 0.5
    beam_skip_error_threshold: 0.9
    beam_skip_threshold: 0.3
    do_beamskip: false
    global_frame_id: "map"
    lambda_short: 0.1
    laser_likelihood_max_dist: 2.0
    laser_max_range: 100.0
    laser_min_range: -1.0
    laser_model_type: "likelihood_field"
    max_beams: 60
    max_particles: 2000
    min_particles: 500
    odom_frame_id: "shark1/odom"
    pf_err: 0.02
    pf_z: 0.85
    recovery_alpha_fast: 0.0
    recovery_alpha_slow: 0.0
    resample_interval: 2
    robot_model_type: "nav2_amcl::DifferentialMotionModel"
    save_pose_rate: 0.5
    sigma_hit: 0.02
    tf_broadcast: true
    transform_tolerance: 1.0
    update_min_a: 0.06
    update_min_d: 0.025
    z_hit: 0.7
    z_max: 0.001
    z_rand: 0.059
    z_short: 0.24
    scan_topic: "scan"
    map_topic: "/map"

    # Initial Pose
    set_initial_pose: True
    initial_pose.x: 2.0
    initial_pose.y: 0.0
    initial_pose.z: 0.0
    initial_pose.yaw: 0.0

shark1/amcl_map_client:
  ros__parameters:
    use_sim_time: False

shark1/amcl_rclcpp_node:
  ros__parameters:
    use_sim_time: False

shark1/bt_navigator:
  ros__parameters:
    use_sim_time: False
    global_frame: map
    robot_base_frame: "shark1/base_footprint"
    odom_topic: "odom" #/지움
    bt_loop_duration: 10
    default_server_timeout: 20
    # 'default_nav_through_poses_bt_xml' and 'default_nav_to_pose_bt_xml' are use defaults:
    # nav2_bt_navigator/navigate_to_pose_w_replanning_and_recovery.xml
    # nav2_bt_navigator/navigate_through_poses_w_replanning_and_recovery.xml
    # They can be set here or via a RewrittenYaml remap from a parent launch file to Nav2.
    plugin_lib_names:
    - nav2_compute_path_to_pose_action_bt_node
    - nav2_compute_path_through_poses_action_bt_node
    - nav2_smooth_path_action_bt_node
    - nav2_follow_path_action_bt_node
    - nav2_spin_action_bt_node
    - nav2_wait_action_bt_node
    - nav2_back_up_action_bt_node
    - nav2_drive_on_heading_bt_node
    - nav2_clear_costmap_service_bt_node
    - nav2_is_stuck_condition_bt_node
    - nav2_goal_reached_condition_bt_node
    - nav2_goal_updated_condition_bt_node
    - nav2_globally_updated_goal_condition_bt_node
    - nav2_is_path_valid_condition_bt_node
    - nav2_initial_pose_received_condition_bt_node
    - nav2_reinitialize_global_localization_service_bt_node
    - nav2_rate_controller_bt_node
    - nav2_distance_controller_bt_node
    - nav2_speed_controller_bt_node
    - nav2_truncate_path_action_bt_node
    - nav2_truncate_path_local_action_bt_node
    - nav2_goal_updater_node_bt_node
    - nav2_recovery_node_bt_node
    - nav2_pipeline_sequence_bt_node
    - nav2_round_robin_node_bt_node
    - nav2_transform_available_condition_bt_node
    - nav2_time_expired_condition_bt_node
    - nav2_path_expiring_timer_condition
    - nav2_distance_traveled_condition_bt_node
    - nav2_single_trigger_bt_node
    # - nav2_goal_updated_controller_bt_node
    - nav2_is_battery_low_condition_bt_node
    - nav2_navigate_through_poses_action_bt_node
    - nav2_navigate_to_pose_action_bt_node
    - nav2_remove_passed_goals_action_bt_node
    - nav2_planner_selector_bt_node
    - nav2_controller_selector_bt_node
    - nav2_goal_checker_selector_bt_node
    - nav2_controller_cancel_bt_node
    - nav2_path_longer_on_approach_bt_node
    - nav2_wait_cancel_bt_node
    - nav2_spin_cancel_bt_node
    - nav2_back_up_cancel_bt_node
    - nav2_drive_on_heading_cancel_bt_node

shark1/bt_navigator_rclcpp_node:
  ros__parameters:
    use_sim_time: False
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

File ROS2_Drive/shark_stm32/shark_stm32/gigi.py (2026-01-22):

#!/usr/bin/env python3
# -*- coding: utf-8 -*-
"""
VelErrorPlotter (ROS 2 Humble, shark_verification)
- 터틀봇3 수동조종키 스타일로 '목표 선속도 v, 각속도 w'를 키보드로 생성/발행(/<ns>/cmd_vel)
- 현재값은 /<ns>/odom 의 twist.twist.linear.x, angular.z 를 사용
- v, w 및 오차(e_v, e_w)를 실시간 그래프로 시각화

키보드 조작(영문자 키):
  선속도 v:     i(↑), ,(콤마: ↓), k(0으로)
  각속도 w:     j(좌+), l(우-),  m(0으로)
  비상정지:     SPACE (v=w=0)
  스텝/최대값:  [=vstep↓] a(작게), s(크게) / z(작게), x(크게)
  종료:         q

그래프:
  상단:  v_target(파랑 실선) vs v_current(파랑 점선)
  중단:  w_target(초록 실선) vs w_current(초록 점선)
  하단:  |e_v|(빨강), |e_w|(주황)

고정 축 범위:
  시간 축: 최근 window_sec 초만 표시 (기본 30s)
  v축: [-vmax*1.2, +vmax*1.2], w축: [-wmax*1.2, +wmax*1.2]
"""

import os
import time
import threading
from collections import deque

import rclpy
from rclpy.node import Node
from geometry_msgs.msg import Twist
from nav_msgs.msg import Odometry

# 무헤드 환경 대응
import matplotlib
if os.environ.get("DISPLAY", "") == "":
    matplotlib.use("Agg")
import matplotlib.pyplot as plt


class VelErrorPlotter(Node):
    def __init__(self):
        super().__init__('vel_error_plotter')

        # ---------------- 파라미터 ----------------
        self.declare_parameter('namespace', 'shark1')     # shark0 | shark1
        self.declare_parameter('v_max', 0.30)             # m/s
        self.declare_parameter('w_max', 1.50)             # rad/s
        self.declare_parameter('v_step', 0.03)            # m/s per key
        self.declare_parameter('w_step', 0.15)            # rad/s per key
        self.declare_parameter('pub_hz', 20.0)            # cmd_vel publish rate
        self.declare_parameter('window_sec', 30.0)        # plot window seconds
        self.declare_parameter('save_fig_path', '')       # Agg일 때 PNG 저장 경로(옵션)
        # -----------------------------------------

        ns           = self.get_parameter('namespace').get_parameter_value().string_value
        self.v_max   = float(self.get_parameter('v_max').get_parameter_value().double_value)
        self.w_max   = float(self.get_parameter('w_max').get_parameter_value().double_value)
        self.v_step  = float(self.get_parameter('v_step').get_parameter_value().double_value)
        self.w_step  = float(self.get_parameter('w_step').get_parameter_value().double_value)
        self.pub_hz  = float(self.get_parameter('pub_hz').get_parameter_value().double_value)
        self.win_sec = float(self.get_parameter('window_sec').get_parameter_value().double_value)
        self.save_png = self.get_parameter('save_fig_path').get_parameter_value().string_value

        # 토픽
        self.topic_cmd  = f'/{ns}/cmd_vel'
        self.topic_odom = f'/{ns}/odom'

        # 퍼블리셔/서브스크라이버
        self.pub_cmd  = self.create_publisher(Twist, self.topic_cmd, 10)
        self.sub_odom = self.create_subscription(Odometry, self.topic_odom, self.cb_odom, 50)

        # 타깃/현재/오차 버퍼
        self.t0 = time.time()
        maxlen = int(self.win_sec * 50)  # 충분히 넉넉히 잡고 시간으로 잘라냄
        self.ts = deque(maxlen=maxlen)

        self.v_tgt = deque(maxlen=maxlen)
        self.w_tgt = deque(maxlen=maxlen)
        self.v_cur = deque(maxlen=maxlen)
        self.w_cur = deque(maxlen=maxlen)
        self.e_v   = deque(maxlen=maxlen)
        self.e_w   = deque(maxlen=maxlen)

        # 목표 속도 (키보드로 제어)
        self._lock = threading.Lock()
        self._v_cmd = 0.0
        self._w_cmd = 0.0

        # cmd_vel 주기 퍼블리시 타이머
        self.create_timer(1.0/max(1e-3, self.pub_hz), self.on_pub_cmd)

        # Matplotlib Figure
        self.fig, (self.ax_v, self.ax_w, self.ax_e) = plt.subplots(3, 1, figsize=(9, 8), sharex=True)
        self.fig.canvas.manager.set_window_title(f"VelErrorPlotter - {ns}")

        # 선 정의
        (self.line_v_tgt,) = self.ax_v.plot([], [], color='#0072BD', lw=1.8, ls='-',  label='v_target [m/s]')
        (self.line_v_cur,) = self.ax_v.plot([], [], color='#0072BD', lw=1.2, ls='--', label='v_current [m/s]')

        (self.line_w_tgt,) = self.ax_w.plot([], [], color='#009E73', lw=1.8, ls='-',  label='w_target [rad/s]')
        (self.line_w_cur,) = self.ax_w.plot([], [], color='#009E73', lw=1.2, ls='--', label='w_current [rad/s]')

        (self.line_e_v,)   = self.ax_e.plot([], [], color='#D55E00', lw=1.6, label='|e_v| [m/s]')
        (self.line_e_w,)   = self.ax_e.plot([], [], color='#EDB120', lw=1.6, label='|e_w| [rad/s]')

        # 축/범례
        pad = 1.2
        self.ax_v.set_ylabel('v [m/s]')
        self.ax_v.set_ylim(-self.v_max*pad, self.v_max*pad)
        self.ax_v.grid(True, linestyle='--', alpha=0.4)
        self.ax_v.legend(loc='upper left')

        self.ax_w.set_ylabel('w [rad/s]')
        self.ax_w.set_ylim(-self.w_max*pad, self.w_max*pad)
        self.ax_w.grid(True, linestyle='--', alpha=0.4)
        self.ax_w.legend(loc='upper left')

        self.ax_e.set_xlabel('time [s]')
        self.ax_e.set_ylabel('abs error')
        self.ax_e.grid(True, linestyle='--', alpha=0.4)
        self.ax_e.legend(loc='upper left')

        # GUI 타이머(메인 스레드에서 주기 갱신)
        self.gui_timer = self.fig.canvas.new_timer(interval=int(1000/10))  # 10 Hz
        self.gui_timer.add_callback(self.update_plot)
        self.gui_timer.start()

        # 키보드 핸들러 등록 (matplotlib 창에 포커스 필요)
        self.fig.canvas.mpl_connect('key_press_event', self.on_key)

        self.get_logger().info(
            f"[VelErrorPlotter] ns={ns}, pub:{self.topic_cmd}, odom:{self.topic_odom}, vmax={self.v_max}, wmax={self.w_max}"
        )

    # ---------------- ROS 콜백 ----------------
    def cb_odom(self, msg: Odometry):
        # 현재 속도 추정 (odom 기준)
        v = float(msg.twist.twist.linear.x)
        w = float(msg.twist.twist.angular.z)
        with self._lock:
            v_cmd = self._v_cmd
            w_cmd = self._w_cmd

        t = time.time() - self.t0
        self.ts.append(t)

        self.v_cur.append(v)
        self.w_cur.append(w)
        self.v_tgt.append(v_cmd)
        self.w_tgt.append(w_cmd)

        self.e_v.append(abs(v - v_cmd))
        self.e_w.append(abs(w - w_cmd))

        # window_sec 유지(시간으로 trim)
        self._trim_window()

    def _trim_window(self):
        # 시간 창 유지: 맨 앞 시간과 현재 시간 비교
        while self.ts and (self.ts[-1] - self.ts[0] > self.win_sec):
            self.ts.popleft()
            self.v_cur.popleft(); self.w_cur.popleft()
            self.v_tgt.popleft(); self.w_tgt.popleft()
            self.e_v.popleft();   self.e_w.popleft()

    # --------------- cmd_vel 퍼블리시 ---------------
    def on_pub_cmd(self):
        with self._lock:
            v = max(-self.v_max, min(self.v_max, self._v_cmd))
            w = max(-self.w_max, min(self.w_max, self._w_cmd))
        msg = Twist()
        msg.linear.x  = v
        msg.angular.z = w
        self.pub_cmd.publish(msg)
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

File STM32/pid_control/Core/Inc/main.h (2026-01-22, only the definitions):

#define B1_Pin GPIO_PIN_13
#define B1_GPIO_Port GPIOC
#define B1_EXTI_IRQn EXTI15_10_IRQn
#define Left_PWM_Pin GPIO_PIN_0
#define Left_PWM_GPIO_Port GPIOA
#define Right_PWM_Pin GPIO_PIN_1
#define Right_PWM_GPIO_Port GPIOA
#define USART_TX_Pin GPIO_PIN_2
#define USART_TX_GPIO_Port GPIOA
#define USART_RX_Pin GPIO_PIN_3
#define USART_RX_GPIO_Port GPIOA
#define LD2_Pin GPIO_PIN_5
#define LD2_GPIO_Port GPIOA
#define left_IN2_Pin GPIO_PIN_4
#define left_IN2_GPIO_Port GPIOC
#define Right_IN1_Pin GPIO_PIN_5
#define Right_IN1_GPIO_Port GPIOC
#define Left_IN1_Pin GPIO_PIN_13
#define Left_IN1_GPIO_Port GPIOB
#define Left_pulse_B_Pin GPIO_PIN_14
#define Left_pulse_B_GPIO_Port GPIOB
#define Left_pulse_B_EXTI_IRQn EXTI15_10_IRQn
#define Left_pulse_A_Pin GPIO_PIN_15
#define Left_pulse_A_GPIO_Port GPIOB
#define Left_pulse_A_EXTI_IRQn EXTI15_10_IRQn
#define Right_IN2_Pin GPIO_PIN_6
#define Right_IN2_GPIO_Port GPIOC
#define HOOK_Input_Pin GPIO_PIN_7
#define HOOK_Input_GPIO_Port GPIOC
#define Actuator1_Lift_Pin GPIO_PIN_8
#define Actuator1_Lift_GPIO_Port GPIOC
#define Actuator2_Lift_Pin GPIO_PIN_9
#define Actuator2_Lift_GPIO_Port GPIOC
#define Actuator1_HOOK_Pin GPIO_PIN_8
#define Actuator1_HOOK_GPIO_Port GPIOA
#define Actuator2_HOOK_Pin GPIO_PIN_9
#define Actuator2_HOOK_GPIO_Port GPIOA
#define Right_pulse_B_Pin GPIO_PIN_11
#define Right_pulse_B_GPIO_Port GPIOA
#define Right_pulse_B_EXTI_IRQn EXTI15_10_IRQn
#define Right_pulse_A_Pin GPIO_PIN_12
#define Right_pulse_A_GPIO_Port GPIOA
#define Right_pulse_A_EXTI_IRQn EXTI15_10_IRQn
#define TMS_Pin GPIO_PIN_13
#define TMS_GPIO_Port GPIOA
#define TCK_Pin GPIO_PIN_14
#define TCK_GPIO_Port GPIOA
#define SWO_Pin GPIO_PIN_3
#define SWO_GPIO_Port GPIOB
#define RAZER_POWER1_Pin GPIO_PIN_8
#define RAZER_POWER1_GPIO_Port GPIOB
#define RAZER_POWER2_Pin GPIO_PIN_9
#define RAZER_POWER2_GPIO_Port GPIOB

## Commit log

2026-01-21 Create STM32
2026-01-22 Shark_utils
    Goal succeeded 발행되면 정렬 패키지 실행

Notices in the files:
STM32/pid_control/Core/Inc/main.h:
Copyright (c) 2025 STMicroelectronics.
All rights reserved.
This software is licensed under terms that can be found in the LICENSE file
